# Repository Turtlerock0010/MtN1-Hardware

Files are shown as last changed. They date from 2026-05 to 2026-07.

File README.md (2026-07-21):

# MtN1-Hardware


> MtN1 Draft 1 3D Model, WIP

> [!IMPORTANT]
> [Check discussions and help out!!! 🥹](https://github.com/Turtlerock0010/MtN1-Hardware/discussions)

> [!NOTE]
> This is the hardware repository for the MtN1! For MtN1 software, go to [MtN1-Lib](https://github.com/Turtlerock0010/MtN1-Lib).

## About

### Q: What is this project?
A: The MtN1 (Motion-1) is a robotics motion expansion board designed to work with any microcontroller that supports QWIIC or I2C!

### Q: What is the goal of this project?
A: The goal of the MtN1 is to ensure complexity is a choice, not a compromise. Although simplicity and constraints allow for mechanisms that are designed with robustness, MtN1 is designed to allow for seasoned and rookie roboticists to truly expand on individual STEM efficacy.

### Q: What was the inspiration for this board?
A: Within MiniFRC -- an event hosted by The Terrorbytes [4561] -- I saw many very impressive creations, ranging from complete swerve drivetrains to advanced vision systems. But one common thread between them were the compromises made in order to work within the bounds of the most common robotics board used. Even I and the MiniFRC team I'm in (The Pink Fluffy Unicorns [83]) deliberated on how to distribute or simplify systems to fit these physical bounds!

### Q: Wait, no microcontroller onboard?
A: Yes!!! The MtN1 does not use a microcontroller. Instead, it uses a distributed control architecture to act as a primative version of one. This allows for cheaper costs, low latency control, universal I2C compatability, and 2 GPIO pin control!

### Q: Why the name MtN1 (Motion-1)?
A: I chose the name MtN1 as I felt like it was the name that properly describes the board's capabilities; and it looks stylish 😎.

## Non-Final Schematic
MtN1 Draft 1

> MtN1 Draft 1 Schematic, WIP

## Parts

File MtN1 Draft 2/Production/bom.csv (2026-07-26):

Designator | Footprint | Quantity | Value | LCSC Part #
C1, C13, C3, C6, C7 | C_0402 | 5 | 0.1uF | C141382
C10, C9 | CP_Elec_6.3x7.7 | 2 | 220uF | C4747974
C12, C2, C4, C5, C8 | C_0402 | 5 | 10uF | C15525
C20, C26 | C_0603 | 2 | 10uF,25V | C96446
C21, C27 | C_0402 | 2 | 100nF | C1525
C22, C28 | C_0402 | 2 | 10pF | C32949
C23, C29 | C_0603 | 2 | 10uF | C19702
D1 | D_SOD-123 | 1 | Z5V6 | C22612
D2 | 0603 | 1 | Green LED | C122984
J1 | C8404_CONN-TH_WJ126V-5_0-2P | 1 | Motor_Port_1 | C8404
J10, J9 | PinHeader_2x03_P2.54mm_Vertical | 2 | ServoPorts_2x3 | C5116479
J11 | JST_SH_BM04B-SRSS-TB_1x04-1MP_P1.00mm_Vertical | 1 | QWIIC | C160390
J12 | JST_SH_BM04B-SRSS-TB_1x04-1MP_P1.00mm_Vertical | 1 | PQWIIC | C160390
J2 | C8404_CONN-TH_WJ126V-5_0-2P | 1 | Motor_Port_2 | C8404
J3 | C8404_CONN-TH_WJ126V-5_0-2P | 1 | Motor_Port_3 | C8404
J4 | C8404_CONN-TH_WJ126V-5_0-2P | 1 | Motor_Port_4 | C8404
J5 | BarrelJack_Horizontal | 1 | Barrel_Jack | C84007
J6 | TestPoint_Pad_2.0x2.0mm | 1 | VIN
J7 | TestPoint_Pad_2.0x2.0mm | 1 | GND
L2, L3 | C98354_IND-SMD_L2_5-W2_0_WPN252012H | 2 | 4.7uH | C98354
Q1 | SOT-23 | 1 | AO3401A | C15127
R1 | R_0603 | 1 | 10kΩ | C25804
R10 | R_0402 | 1 | 68kΩ | C2909379
R11 | R_0402 | 1 | 4k7Ω | C25900
R12 | R_0402 | 1 | 15kΩ | C25756
R13 | C25744_R0402 | 1 | 10kΩ | C25744
R2 | R_0402 | 1 | 1kΩ | C11702
R3, R5, R6 | R_0402 | 3 | 10kΩ | C25744
R9 | R_0402 | 1 | 33kΩ | C25779
SW1 | C2681588_SW-TH_5_8ZSPT | 1 | 5.8 ZSPT | C2681588
U1, U2 | SSOP-24_5.3x8.2mm_P0.65mm | 2 | TB6612FNG | C88224
U5 | QFN-28-1EP_6x6mm_P0.65mm_EP4.25x4.25mm | 1 | PCA9685BS | C5191634
U6, U7 | C78989_TSOT-23-6_L2_9-W1_6-P0_95-LS2_8-BR | 2 | SY8113BADC | C78989

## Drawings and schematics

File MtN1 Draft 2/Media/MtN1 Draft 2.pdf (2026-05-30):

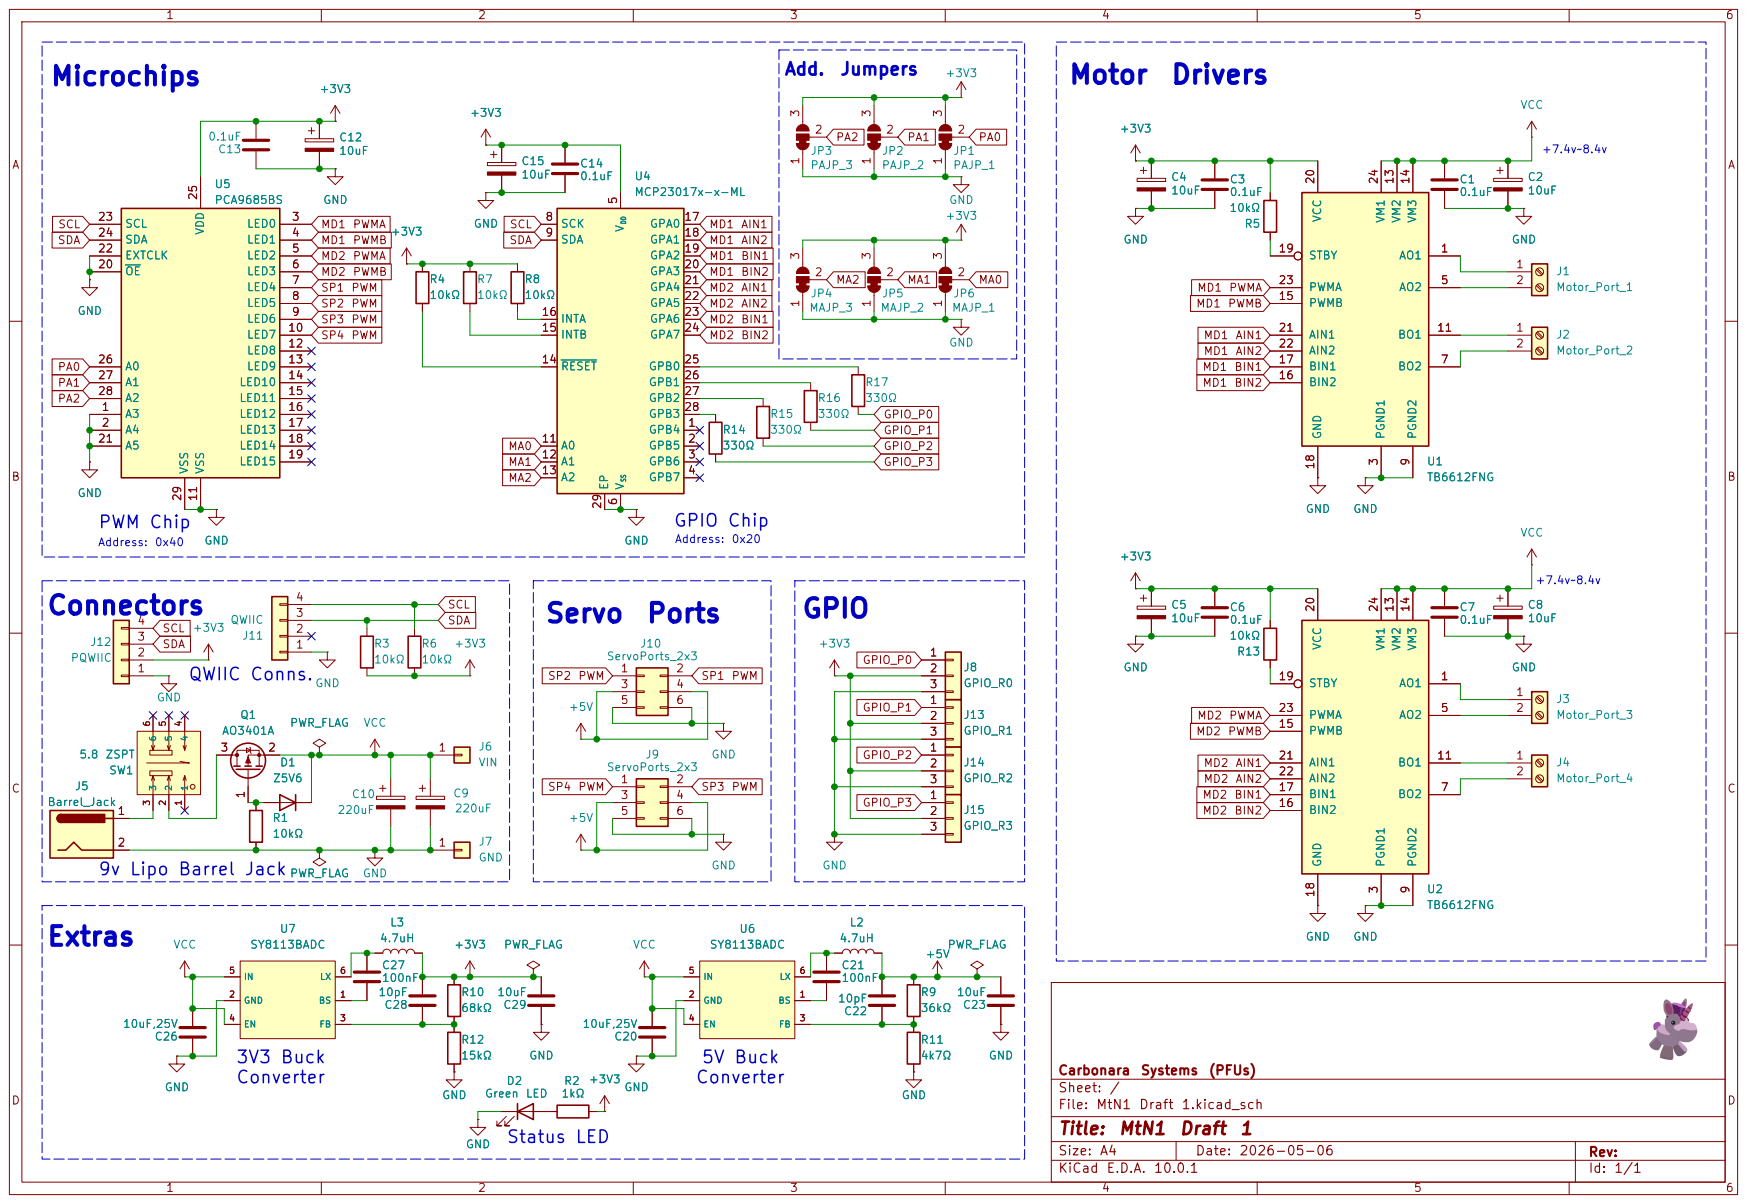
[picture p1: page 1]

SCK 8
SDA 9
- Readdressing is not for beginners! - Must use proper tools - Allowed but not recommended - GND & 3V3 tied together causes short-circuit! - Motor & servo port expansion! - Qwiic expansion board! - Qwiic pass through! - Extra GPIO! - "Robust" power handling! - Simple library control! Servo Ports

Size: A4 | Rev:
KiCad E.D.A. 10.0.1 | Id: 1/1

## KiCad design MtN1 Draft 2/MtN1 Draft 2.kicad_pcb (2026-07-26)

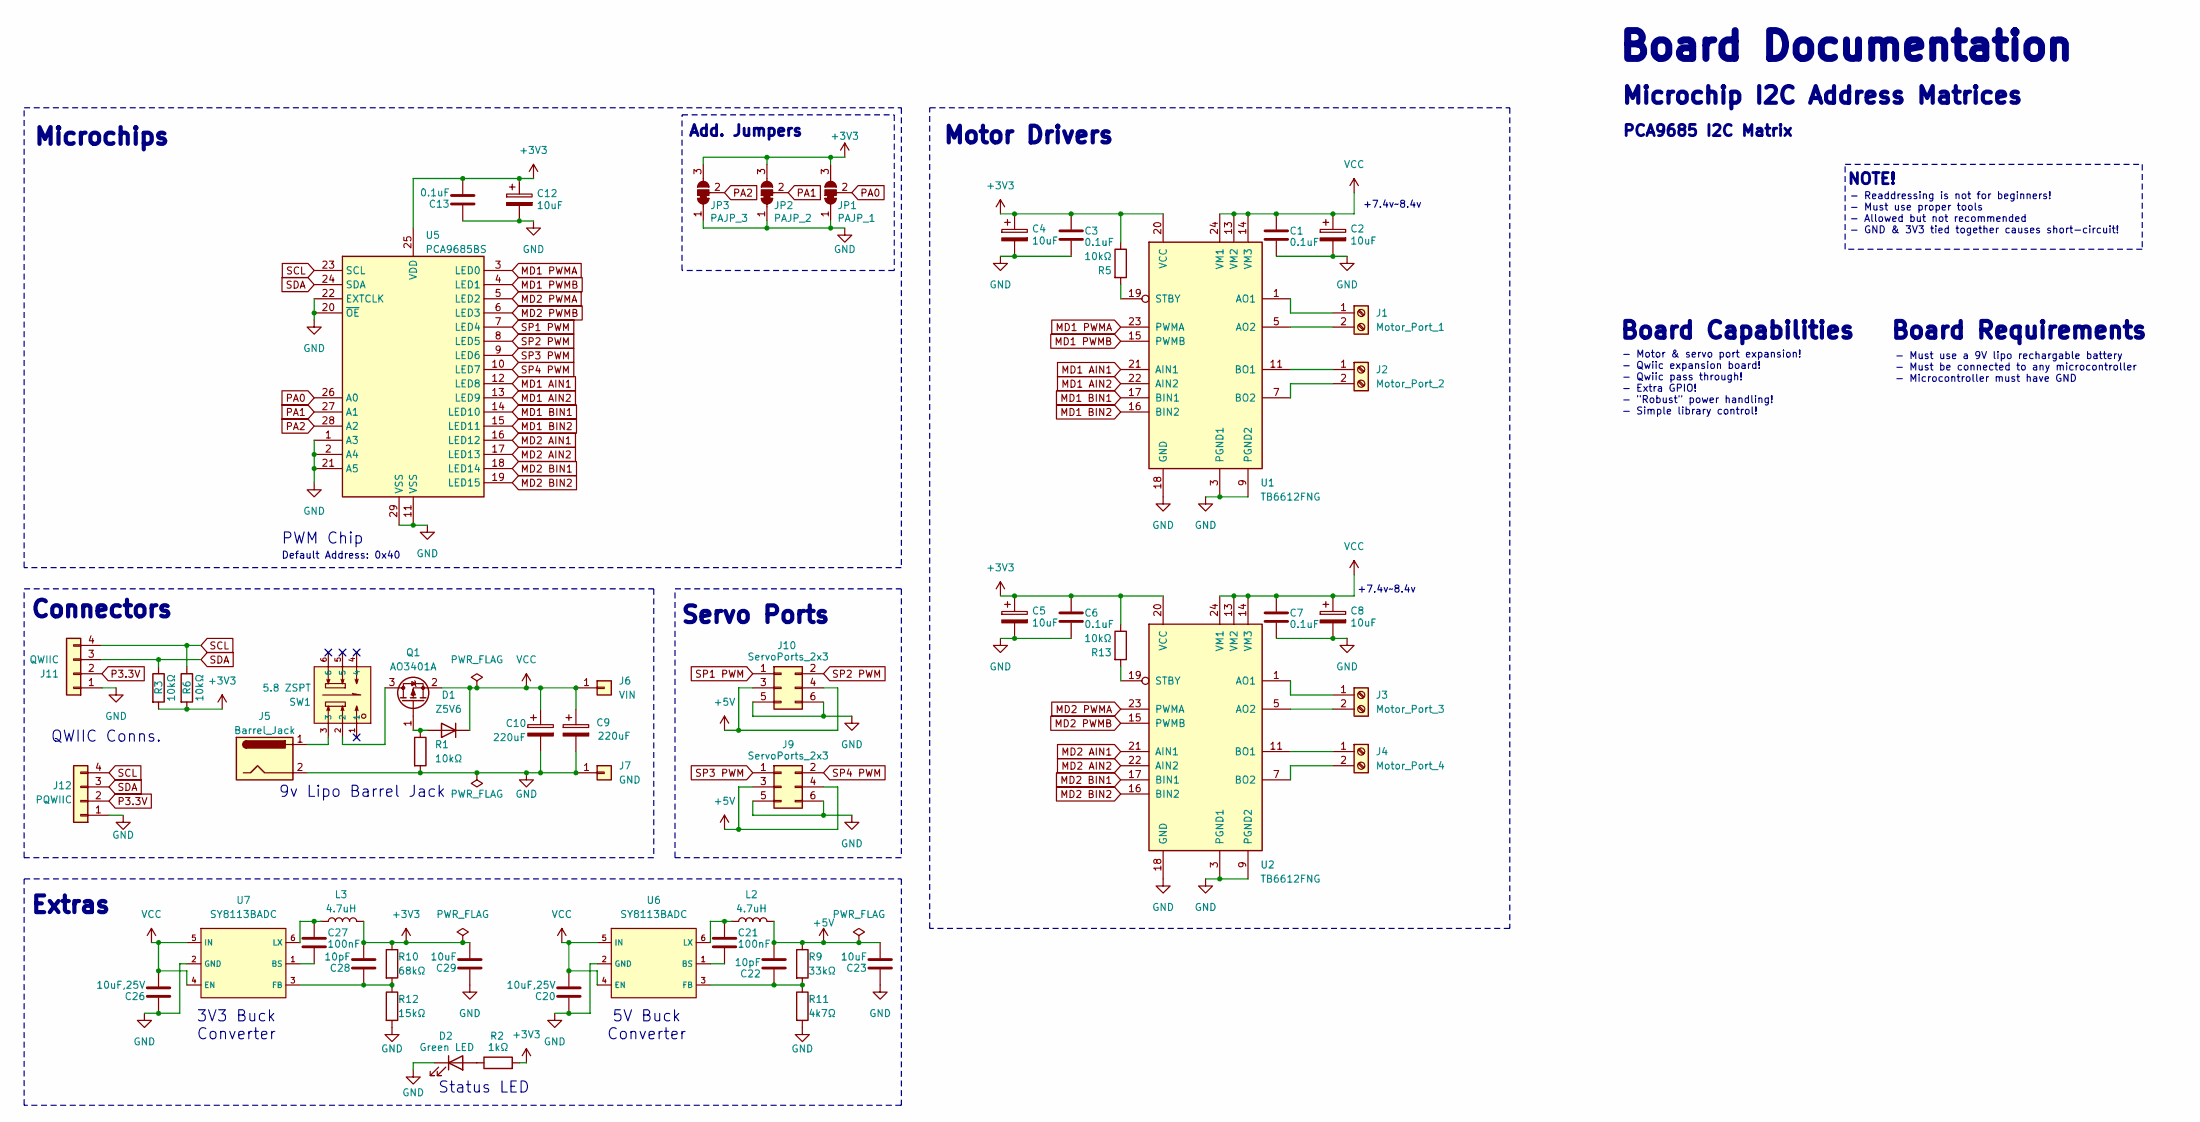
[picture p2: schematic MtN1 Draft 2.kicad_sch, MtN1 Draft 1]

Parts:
C1, C3, C6, C7, C13: 0.1uF; C_0402
C2, C4, C5, C8, C12: 10uF; C_0402
C9, C10: 220uF; CP_Elec_6.3x7.7
C20, C26: 10uF,25V; C_0603
C21, C27: 100nF; C_0402
C22, C28: 10pF; C_0402
C23, C29: 10uF; C_0603
D1: Z5V6; D_SOD-123
D2: Green LED; LED_0603_1608Metric
J1: Motor_Port_1; C8404_CONN-TH_WJ126V-5_0-2P
J2: Motor_Port_2; C8404_CONN-TH_WJ126V-5_0-2P
J3: Motor_Port_3; C8404_CONN-TH_WJ126V-5_0-2P
J4: Motor_Port_4; C8404_CONN-TH_WJ126V-5_0-2P
J5: Barrel_Jack; BarrelJack_Horizontal
J6: VIN; TestPoint_Pad_2.0x2.0mm
J7: GND; TestPoint_Pad_2.0x2.0mm
J9, J10: ServoPorts_2x3; PinHeader_2x03_P2.54mm_Vertical
J11: QWIIC; JST_SH_BM04B-SRSS-TB_1x04-1MP_P1.00mm_Vertical
J12: PQWIIC; JST_SH_BM04B-SRSS-TB_1x04-1MP_P1.00mm_Vertical
JP1: PAJP_1; SolderJumper-3_P1.3mm_Bridged12_RoundedPad1.0x1.5mm
JP2: PAJP_2; SolderJumper-3_P1.3mm_Bridged12_RoundedPad1.0x1.5mm
JP3: PAJP_3; SolderJumper-3_P1.3mm_Bridged12_RoundedPad1.0x1.5mm
L2, L3: 4.7uH; C98354_IND-SMD_L2_5-W2_0_WPN252012H
Q1: AO3401A; SOT-23
R1: 10kΩ; R_0603
R2: 1kΩ; R_0402
R3, R5, R6: 10kΩ; R_0402
R9: 33kΩ; R_0402
R10: 68kΩ; R_0402
R11: 4k7Ω; R_0402
R12: 15kΩ; R_0402
R13: 10kΩ; C25744_R0402
SW1: 5.8 ZSPT; C2681588_SW-TH_5_8ZSPT; LCSC C2681588
U1, U2: TB6612FNG; SSOP-24_5.3x8.2mm_P0.65mm
U5: PCA9685BS; QFN-28-1EP_6x6mm_P0.65mm_EP4.25x4.25mm
U6, U7: SY8113BADC; C78989_TSOT-23-6_L2_9-W1_6-P0_95-LS2_8-BR; LCSC C78989

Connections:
+3V3: C3.1, C4.1, C5.1, C6.1, C12.1, C13.2, C28.2, C29.2, JP1.3 (B), JP2.3 (B), JP3.3 (B), L3.2, R2.2, R3.2, R5.1, R6.2, R10.1, R13.1, U1.20 (VCC), U2.20 (VCC), U5.25 (VDD)
+5V: C22.2, C23.2, J9.3, J9.4, J10.3, J10.4, L2.2, R9.1
GND: C1.2, C2.2, C3.2, C4.2, C5.2, C6.2, C7.2, C8.2, C9.2, C10.2, C12.2, C13.1, C20.1, C23.1, C26.1, C29.1, D2.1 (K), J5.2, J7.1 (Pin_1_1), J9.5, J9.6, J10.5, J10.6, J11.1, J12.1, JP1.1 (A), JP2.1 (A), JP3.1 (A), R1.2, R11.2, R12.2, U1.3 (PGND1), U1.4 (PGND1), U1.9 (PGND2), U1.10 (PGND2), U1.18 (GND), U2.3 (PGND1), U2.4 (PGND1), U2.9 (PGND2), U2.10 (PGND2), U2.18 (GND), U5.1 (A3), U5.2 (A4), U5.11 (VSS), U5.20 (~OE), U5.21 (A5), U5.22 (EXTCLK), U5.29 (VSS), U6.2 (GND), U7.2 (GND)
MD1 AIN1: U1.21 (AIN1), U5.12 (LED8)
MD1 AIN2: U1.22 (AIN2), U5.13 (LED9)
MD1 BIN1: U1.17 (BIN1), U5.14 (LED10)
MD1 BIN2: U1.16 (BIN2), U5.15 (LED11)
MD1 PWMA: U1.23 (PWMA), U5.3 (LED0)
MD1 PWMB: U1.15 (PWMB), U5.4 (LED1)
MD2 AIN1: U2.21 (AIN1), U5.16 (LED12)
MD2 AIN2: U2.22 (AIN2), U5.17 (LED13)
MD2 BIN1: U2.17 (BIN1), U5.18 (LED14)
MD2 BIN2: U2.16 (BIN2), U5.19 (LED15)
MD2 PWMA: U2.23 (PWMA), U5.5 (LED2)
MD2 PWMB: U2.15 (PWMB), U5.6 (LED3)
unnamed: D1.2 (A), Q1.1 (G), R1.1
unnamed: D2.2 (A), R2.1
unnamed: J1.1, U1.1 (AO1), U1.2 (AO1)
unnamed: J1.2, U1.5 (AO2), U1.6 (AO2)
unnamed: J2.1, U1.11 (BO1), U1.12 (BO1)
unnamed: J2.2, U1.7 (BO2), U1.8 (BO2)
unnamed: J3.1, U2.1 (AO1), U2.2 (AO1)
unnamed: J3.2, U2.5 (AO2), U2.6 (AO2)
unnamed: J4.1, U2.11 (BO1), U2.12 (BO1)
unnamed: J4.2, U2.7 (BO2), U2.8 (BO2)
unnamed: J5.1, SW1.3
unnamed: Q1.3 (D), SW1.2
unnamed: R5.2, U1.19 (STBY)
unnamed: R13.2, U2.19 (STBY)
unnamed: C21.1, U6.1 (BS)
unnamed: C22.1, R9.2, R11.1, U6.3 (FB)
unnamed: C21.2, L2.1, U6.6 (LX)
unnamed: C27.1, U7.1 (BS)
unnamed: C28.1, R10.2, R12.1, U7.3 (FB)
unnamed: C27.2, L3.1, U7.6 (LX)
P3.3V: J11.2, J12.2
PA0: JP1.2 (C), U5.26 (A0)
PA1: JP2.2 (C), U5.27 (A1)
PA2: JP3.2 (C), U5.28 (A2)
SCL: J11.4, J12.4, R6.1, U5.23 (SCL)
SDA: J11.3, J12.3, R3.1, U5.24 (SDA)
SP1 PWM: J10.1, U5.7 (LED4)
SP2 PWM: J10.2, U5.8 (LED5)
SP3 PWM: J9.1, U5.9 (LED6)
SP4 PWM: J9.2, U5.10 (LED7)
VCC: C1.1, C2.1, C7.1, C8.1, C9.1, C10.1, C20.2, C26.2, D1.1 (K), J6.1 (Pin_1_1), Q1.2 (S), U1.13 (VM2), U1.14 (VM3), U1.24 (VM1), U2.13 (VM2), U2.14 (VM3), U2.24 (VM1), U6.4 (EN), U6.5 (IN), U7.4 (EN), U7.5 (IN)

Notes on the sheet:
QWIIC Conns.
Microchip I2C Address Matrices
3V3 Buck Converter
9v Lipo Barrel Jack
Status LED
5V Buck Converter
Default Address: 0x40
- Readdressing is not for beginners! - Must use proper tools - Allowed but not recommended - GND & 3V3 tied together causes short-circuit!
+7.4v~8.4v
Servo Ports
PWM Chip
- Motor & servo port expansion! - Qwiic expansion board! - Qwiic pass through! - Extra GPIO! - "Robust" power handling! - Simple library control!
PCA9685 I2C Matrix
Board Requirements
Microchips
NOTE!
Board Documentation
Connectors
- Must use a 9V lipo rechargable battery - Must be connected to any microcontroller - Microcontroller must have GND
Extras
Motor Drivers
Board Capabilities
Add. Jumpers

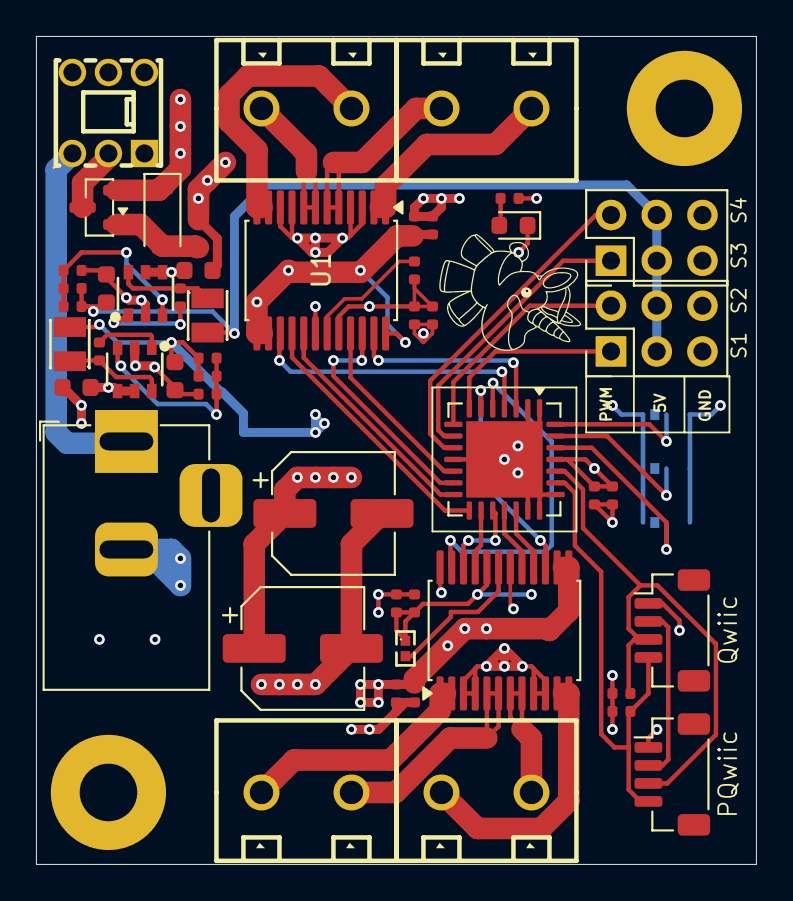
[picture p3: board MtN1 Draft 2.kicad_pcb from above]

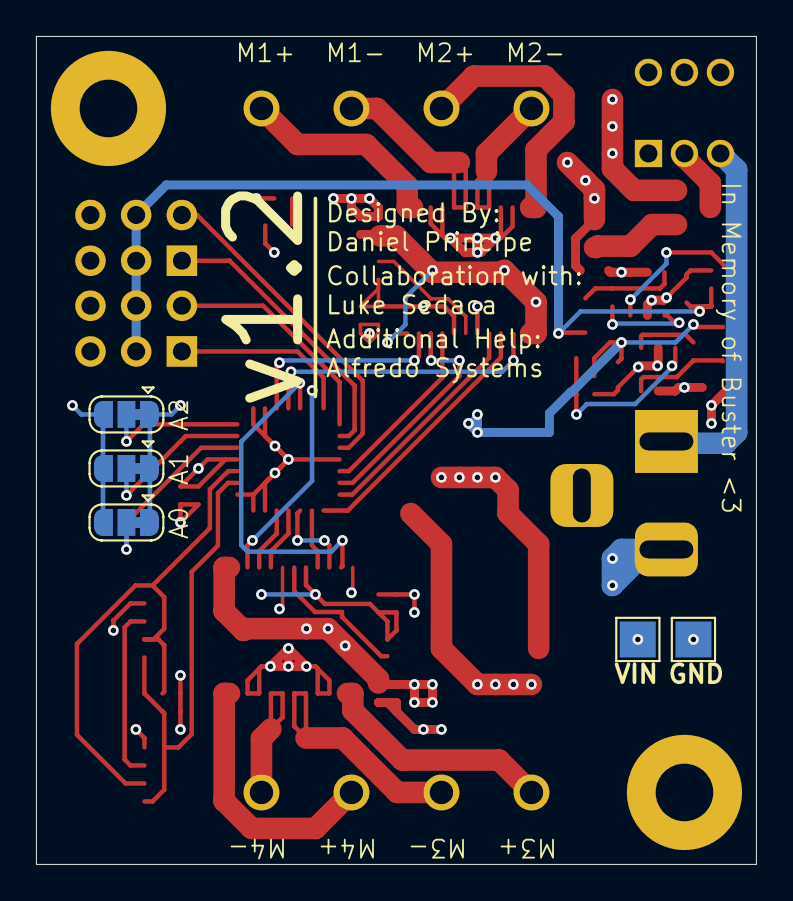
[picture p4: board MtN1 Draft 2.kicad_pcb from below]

Board: 4 copper layers, 40.0 x 46.0 mm, 55 parts (5 on the bottom side), 46 nets.

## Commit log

2026-05-22 Updated project files up to Article 2
    [MtN1 Draft 1.kicad_pcb, MtN1 Draft 1.kicad_sch]
2026-05-23 Updated project files up to Article 3
    [MtN1 Draft 1.kicad_pcb, MtN1 Draft 1.kicad_sch]
2026-05-23 Update README with MtN1 Draft 1 links and images
    Added links to MtN1 Draft 1 PDF files and updated schematic image.
2026-05-30 Add .gitignore to ignore local KiCad backups
    guys... its so much backups 😭
2026-05-30 Adding files for Article 5
    I can't do the article rn, but sometime later.
    [MtN1 Draft 1.kicad_pcb]
2026-05-30 Github Desktop stuff
    [MtN1 Draft 1.kicad_pcb]
2026-05-30 Updated project files for Article 5
    Article 5 isn't done yet, but just updating files for the future when it is done.
    [MtN1 Draft 1.kicad_pcb, MtN1 Draft 1.kicad_sch]
2026-05-30 PCB layout cleanup
    I'm going to get absolutely obliterated the second I show this off 💔
    [MtN1 Draft 1.kicad_pcb]
2026-05-31 Trace cleanup; extra labels
    DRC likes me now 🎉, but probably not someone who understands electronics 😭
    [MtN1 Draft 1.kicad_pcb]
2026-06-12 Added Note To Silkscreen
    [MtN1 Draft 1.kicad_pcb]
2026-07-21 Update .gitignore to include KiCad temporary files
    Added various temporary and backup file patterns to .gitignore.
2026-07-21 Draft 2 & Board Redo
    [MtN1 Draft 2.kicad_pcb, MtN1 Draft 2.kicad_sch]
2026-07-21 Added new .STEP file
    [MtN1 Draft 2.kicad_pcb]
2026-07-25 Draft 2 Changes; Part assignments
    [MtN1 Draft 2.kicad_pcb, MtN1 Draft 2.kicad_sch, bom.csv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]
2026-07-26 Adjusted production files
    [MtN1 Draft 2.kicad_pcb, bom.csv]
